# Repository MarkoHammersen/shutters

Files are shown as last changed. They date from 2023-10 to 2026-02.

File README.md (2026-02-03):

# ESP32 Shutter Control System
This project implements a **ESP32-based shutter control system** designed for controlling shutter motors via relays, with clear separation between hardware abstraction and business logic.
The system combines **ESP32**, **Microchip MCP23017 I/O expanders**, and **ULN2003A Darlington arrays**, and is implemented in **C++ using PlatformIO with the Arduino framework**.

---

## System Overview
The shutter system consists of:

* An **ESP32** as the central controller
* **MCP23017 I/O expanders** for scalable digital input and output via I²C
* **ULN2003A Darlington transistor arrays** for driving relay coils
* A dedicated **external 5 V power supply** for stable I/O operation

All safety-relevant design aspects (galvanic separation, flyback protection, low coil current) are explicitly addressed in the extern hardware design, which is not part of the schematics attached.

---

## Hardware Architecture

### Inputs (Buttons / Wall Switches)

* Digital inputs are handled by an **MCP23017 configured as input expander**
* Button **press and release events** are captured
* Each input event triggers a **hardware interrupt**
* The interrupt line is connected to the ESP32
* Upon interrupt, the ESP32:

  1. Starts an I²C transaction
  2. Reads the MCP23017 input registers
  3. Determines the exact event (press or release)

This approach ensures:

* Low latency
* Minimal polling
* Efficient I²C bus usage

---

### Outputs (Shutter Actuation)

* Outputs are handled by a second **MCP23017 configured as output expander**
* Output states are sent from the ESP32 via **I²C**
* MCP23017 outputs drive **ULN2003A Darlington arrays**
* The Darlington arrays drive the **relay coils**

#### Relay Driving

* Relay coil current is low enough to be **safely driven by ULN2003A**
* **Flyback diodes** are mounted directly at the relay coils
* This protects the Darlington arrays and improves EMC robustness

> ⚠️ **Note:** Mains voltage must only be handled by qualified personnel.
---

### Power Supply

* All MCP23017 inputs and outputs are powered by a **stable external 5 V supply**
* This ensures:

  * Reliable logic levels
  * Noise immunity
  * Stable operation independent of ESP32 load conditions

---

## Software Architecture

The firmware is written in **C++** and built using:

* **PlatformIO**
* **Arduino framework**
* **ESP32 target**

The software is cleanly structured into three main layers using dedicated FreeRTOS tasks. The communication between these tasks are done via message queues:

### 1. Sensors

* Abstraction of all input devices
* MCP23017 input handling
* Interrupt processing
* Debouncing and event detection (press / release)

### 2. Actuators

* Abstraction of all output devices
* MCP23017 output handling
* Relay control logic
* Hardware-independent actuator interface

### 3. Shutter Business Logic

* High-level shutter control logic
* Direction handling (up / down)
* Timing and safety constraints
* Mutual exclusion of motor directions

#### State Machine

The business logic is implemented using a **state machine** based on:

👉 **Quantum Leaps – State-Oriented Programming**
[https://github.com/QuantumLeaps/State-Oriented-Programming](https://github.com/QuantumLeaps/State-Oriented-Programming)

This provides:

* Explicit, deterministic state handling
* Clear separation of states and events
* Improved maintainability and testability
* Robust behavior for asynchronous events (buttons, interrupts)

---

## Documentation & Schematics

* Hardware schematics are included in the repository

---

## Key Features

* ESP32-based central control
* Interrupt-driven input handling
* Scalable I/O via MCP23017
* Safe relay driving using ULN2003A
* Clear separation of concerns in software
* State-machine-driven business logic

---
### ⚠️ WARNING

This project uses electromechanical actuators.
Improper handling can result in serious injury, fire, or death.

This project is provided for educational and experimental purposes only.
The author assumes no liability for any damage, injury, or loss resulting
from the use, misuse, or modification of this hardware or software.

Only qualified personnel should work with mains voltage systems.

---
This project is not certified for commercial or residential use.
No compliance with CE, VDE, UL, or any other safety standard is claimed.
--
Use at your own risk!

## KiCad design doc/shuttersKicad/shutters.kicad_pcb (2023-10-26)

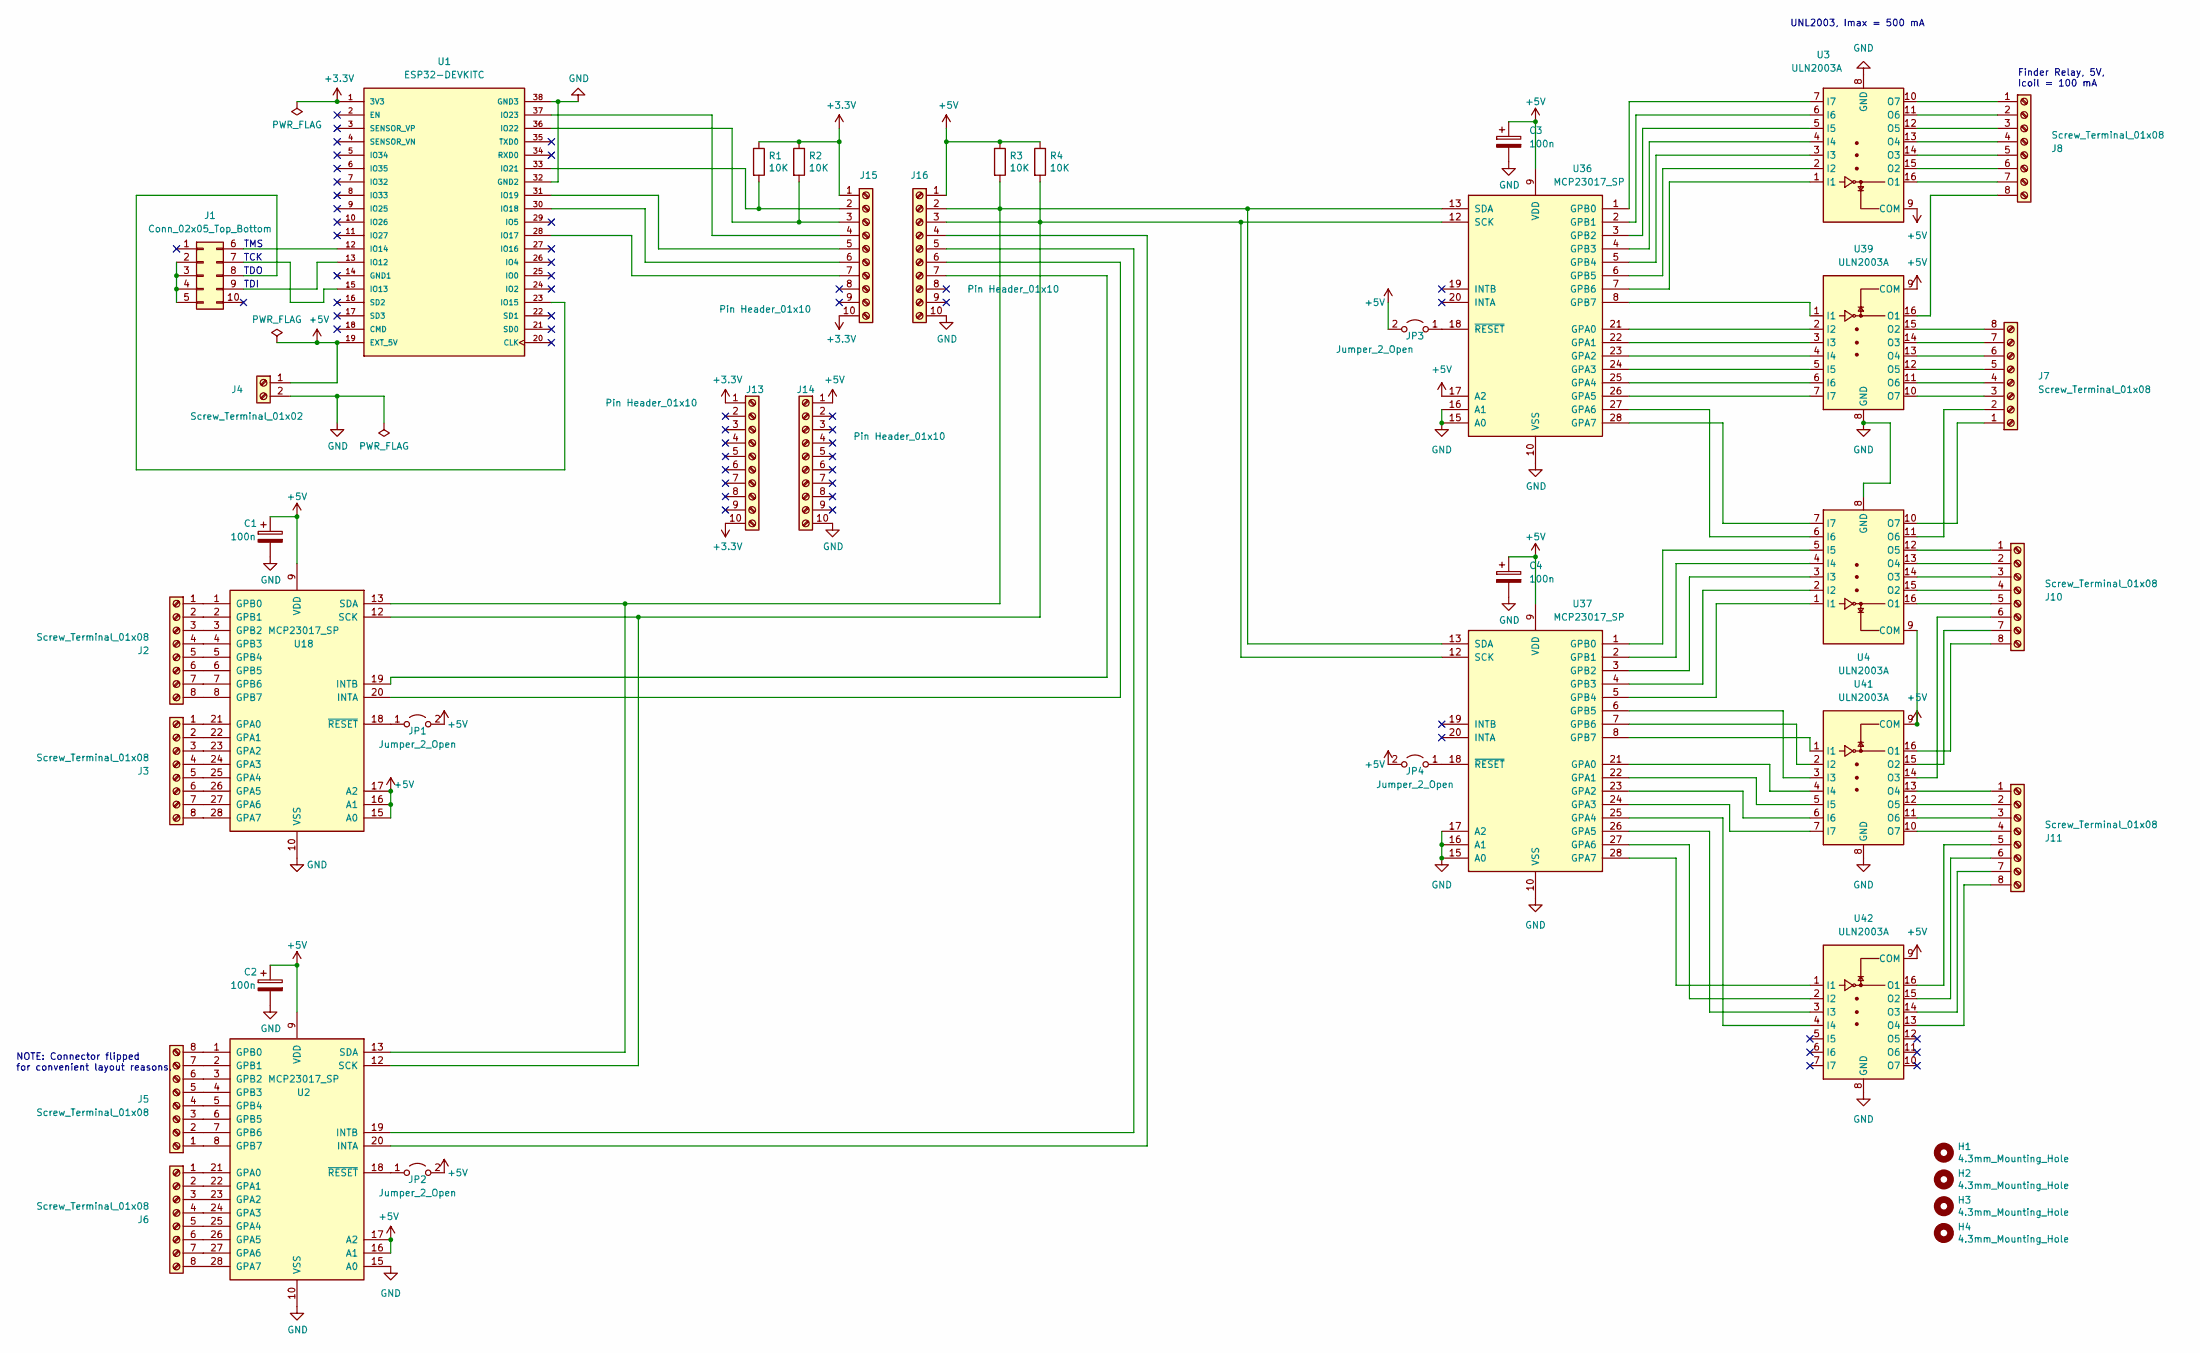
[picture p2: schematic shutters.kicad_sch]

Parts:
C1, C2, C3, C4: 100n; C_Rect_L7.0mm_W2.5mm_P5.00mm
H1, H2, H3, H4: 4.3mm_Mounting_Hole; MountingHole_4.3mm_M4
J1: Conn_02x05_Top_Bottom; PinHeader_2x05_P2.54mm_Vertical
J2, J3, J5, J6, J7, J8, J10, J11: Screw_Terminal_01x08; TerminalBlock_Phoenix_MKDS-1,5-8-5.08_1x08_P5.08mm_Horizont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
J4: Screw_Terminal_01x02; TerminalBlock_Phoenix_MKDS-1,5-2-5.08_1x02_P5.08mm_Horizont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
J13, J14, J15, J16: Pin Header_01x10; PinHeader_1x10_P2.54mm_Vertical
JP1, JP2, JP3, JP4: Jumper_2_Open; PinHeader_1x02_P2.54mm_Vertical
R1, R2, R3, R4: 10K; R_Axial_DIN0204_L3.6mm_D1.6mm_P5.08mm_Horizontal
U1: ESP32-DEVKITC; MODULE_ESP32-DEVKITC; PARTREV N/A
U2, U18, U36, U37: MCP23017_SP; DIP-28_W7.62mm
U3, U4, U39, U41, U42: ULN2003A; DIP-16_W7.62mm_Socket

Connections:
+3V3: J13.1, J13.10, J15.1, J15.10, R1.1, R2.1, U1.1 (3V3)
+5V: C1.1, C2.1, C3.1, C4.1, J4.1, J14.1, J16.1, JP1.2 (B), JP2.2 (B), JP3.2 (B), JP4.2 (B), R3.1, R4.1, U1.19 (EXT_5V), U2.9 (VDD), U2.16 (A1), U2.17 (A2), U3.9 (COM), U4.9 (COM), U18.9 (VDD), U18.15 (A0), U18.16 (A1), U18.17 (A2), U36.9 (VDD), U36.17 (A2), U37.9 (VDD), U39.9 (COM), U41.9 (COM), U42.9 (COM)
GND: C1.2, C2.2, C3.2, C4.2, J4.2, J14.10, J16.10, U1.32 (GND2), U1.38 (GND3), U2.10 (VSS), U2.15 (A0), U3.8 (GND), U4.8 (GND), U18.10 (VSS), U36.10 (VSS), U36.15 (A0), U36.16 (A1), U37.10 (VSS), U37.15 (A0), U37.16 (A1), U37.17 (A2), U39.8 (GND), U41.8 (GND), U42.8 (GND)
unnamed: J1.2, J1.3, J1.4, J1.5
unnamed: J1.6, U1.12 (IO14)
unnamed: J1.7, U1.15 (IO13)
unnamed: J1.8, U1.23 (IO15)
unnamed: J1.9, U1.13 (IO12)
unnamed: J2.1, U18.1 (GPB0)
unnamed: J2.2, U18.2 (GPB1)
unnamed: J2.3, U18.3 (GPB2)
unnamed: J2.4, U18.4 (GPB3)
unnamed: J2.5, U18.5 (GPB4)
unnamed: J2.6, U18.6 (GPB5)
unnamed: J2.7, U18.7 (GPB6)
unnamed: J2.8, U18.8 (GPB7)
unnamed: J3.1, U18.21 (GPA0)
unnamed: J3.2, U18.22 (GPA1)
unnamed: J3.3, U18.23 (GPA2)
unnamed: J3.4, U18.24 (GPA3)
unnamed: J3.5, U18.25 (GPA4)
unnamed: J3.6, U18.26 (GPA5)
unnamed: J3.7, U18.27 (GPA6)
unnamed: J3.8, U18.28 (GPA7)
unnamed: J5.1, U2.8 (GPB7)
unnamed: J5.2, U2.7 (GPB6)
unnamed: J5.3, U2.6 (GPB5)
unnamed: J5.4, U2.5 (GPB4)
unnamed: J5.5, U2.4 (GPB3)
unnamed: J5.6, U2.3 (GPB2)
unnamed: J5.7, U2.2 (GPB1)
unnamed: J5.8, U2.1 (GPB0)
unnamed: J6.1, U2.21 (GPA0)
unnamed: J6.2, U2.22 (GPA1)
unnamed: J6.3, U2.23 (GPA2)
unnamed: J6.4, U2.24 (GPA3)
unnamed: J6.5, U2.25 (GPA4)
unnamed: J6.6, U2.26 (GPA5)
unnamed: J6.7, U2.27 (GPA6)
unnamed: J6.8, U2.28 (GPA7)
unnamed: J7.1, U4.10 (O7)
unnamed: J7.2, U4.11 (O6)
unnamed: J7.3, U39.10 (O7)
unnamed: J7.4, U39.11 (O6)
unnamed: J7.5, U39.12 (O5)
unnamed: J7.6, U39.13 (O4)
unnamed: J7.7, U39.14 (O3)
unnamed: J7.8, U39.15 (O2)
unnamed: J8.1, U3.10 (O7)
unnamed: J8.2, U3.11 (O6)
unnamed: J8.3, U3.12 (O5)
unnamed: J8.4, U3.13 (O4)
unnamed: J8.5, U3.14 (O3)
unnamed: J8.6, U3.15 (O2)
unnamed: J8.7, U3.16 (O1)
unnamed: J8.8, U39.16 (O1)
unnamed: J10.1, U4.12 (O5)
unnamed: J10.2, U4.13 (O4)
unnamed: J10.3, U4.14 (O3)
unnamed: J10.4, U4.15 (O2)
unnamed: J10.5, U4.16 (O1)
unnamed: J10.6, U41.14 (O3)
unnamed: J10.7, U41.15 (O2)
unnamed: J10.8, U41.16 (O1)
unnamed: J11.1, U41.13 (O4)
unnamed: J11.2, U41.12 (O5)
unnamed: J11.3, U41.11 (O6)
unnamed: J11.4, U41.10 (O7)
unnamed: J11.5, U42.16 (O1)
unnamed: J11.6, U42.15 (O2)
unnamed: J11.7, U42.14 (O3)
unnamed: J11.8, U42.13 (O4)
unnamed: J15.2, R1.2, U1.33 (IO21)
unnamed: J15.3, R2.2, U1.36 (IO22)
unnamed: J15.4, U1.37 (IO23)
unnamed: J15.5, U1.31 (IO19)
unnamed: J15.6, U1.30 (IO18)
unnamed: J15.7, U1.28 (IO17)
unnamed: J16.2, R3.2, U2.13 (SDA), U18.13 (SDA), U36.13 (SDA), U37.13 (SDA)
unnamed: J16.3, R4.2, U2.12 (SCK), U18.12 (SCK), U36.12 (SCK), U37.12 (SCK)
unnamed: J16.4, U2.20 (INTA)
unnamed: J16.5, U2.19 (INTB)
unnamed: J16.6, U18.20 (INTA)
unnamed: J16.7, U18.19 (INTB)
unnamed: JP1.1 (A), U18.18 (~RESET)
unnamed: JP2.1 (A), U2.18 (~RESET)
unnamed: JP3.1 (A), U36.18 (~RESET)
unnamed: JP4.1 (A), U37.18 (~RESET)
unnamed: U3.1 (I1), U36.7 (GPB6)
unnamed: U3.2 (I2), U36.6 (GPB5)
unnamed: U3.3 (I3), U36.5 (GPB4)
unnamed: U3.4 (I4), U36.4 (GPB3)
unnamed: U3.5 (I5), U36.3 (GPB2)
unnamed: U3.6 (I6), U36.2 (GPB1)
unnamed: U3.7 (I7), U36.1 (GPB0)
unnamed: U36.8 (GPB7), U39.1 (I1)
unnamed: U36.21 (GPA0), U39.2 (I2)
unnamed: U36.22 (GPA1), U39.3 (I3)
unnamed: U36.23 (GPA2), U39.4 (I4)
unnamed: U36.24 (GPA3), U39.5 (I5)
unnamed: U36.25 (GPA4), U39.6 (I6)
unnamed: U36.26 (GPA5), U39.7 (I7)
unnamed: U4.6 (I6), U36.27 (GPA6)
unnamed: U4.7 (I7), U36.28 (GPA7)
unnamed: U4.5 (I5), U37.1 (GPB0)
unnamed: U4.4 (I4), U37.2 (GPB1)
unnamed: U4.3 (I3), U37.3 (GPB2)
unnamed: U4.2 (I2), U37.4 (GPB3)
unnamed: U4.1 (I1), U37.5 (GPB4)
unnamed: U37.6 (GPB5), U41.3 (I3)
unnamed: U37.7 (GPB6), U41.2 (I2)
unnamed: U37.8 (GPB7), U41.1 (I1)
unnamed: U37.21 (GPA0), U41.4 (I4)
unnamed: U37.22 (GPA1), U41.5 (I5)
unnamed: U37.23 (GPA2), U41.6 (I6)
unnamed: U37.24 (GPA3), U41.7 (I7)
unnamed: U37.25 (GPA4), U42.4 (I4)
unnamed: U37.26 (GPA5), U42.3 (I3)
unnamed: U37.27 (GPA6), U42.2 (I2)
unnamed: U37.28 (GPA7), U42.1 (I1)

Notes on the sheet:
UNL2003, Imax = 500 mA
Finder Relay, 5V, Icoil = 100 mA
TMS
TCK
TDO
NOTE: Connector flipped for convenient layout reasons.
TDI

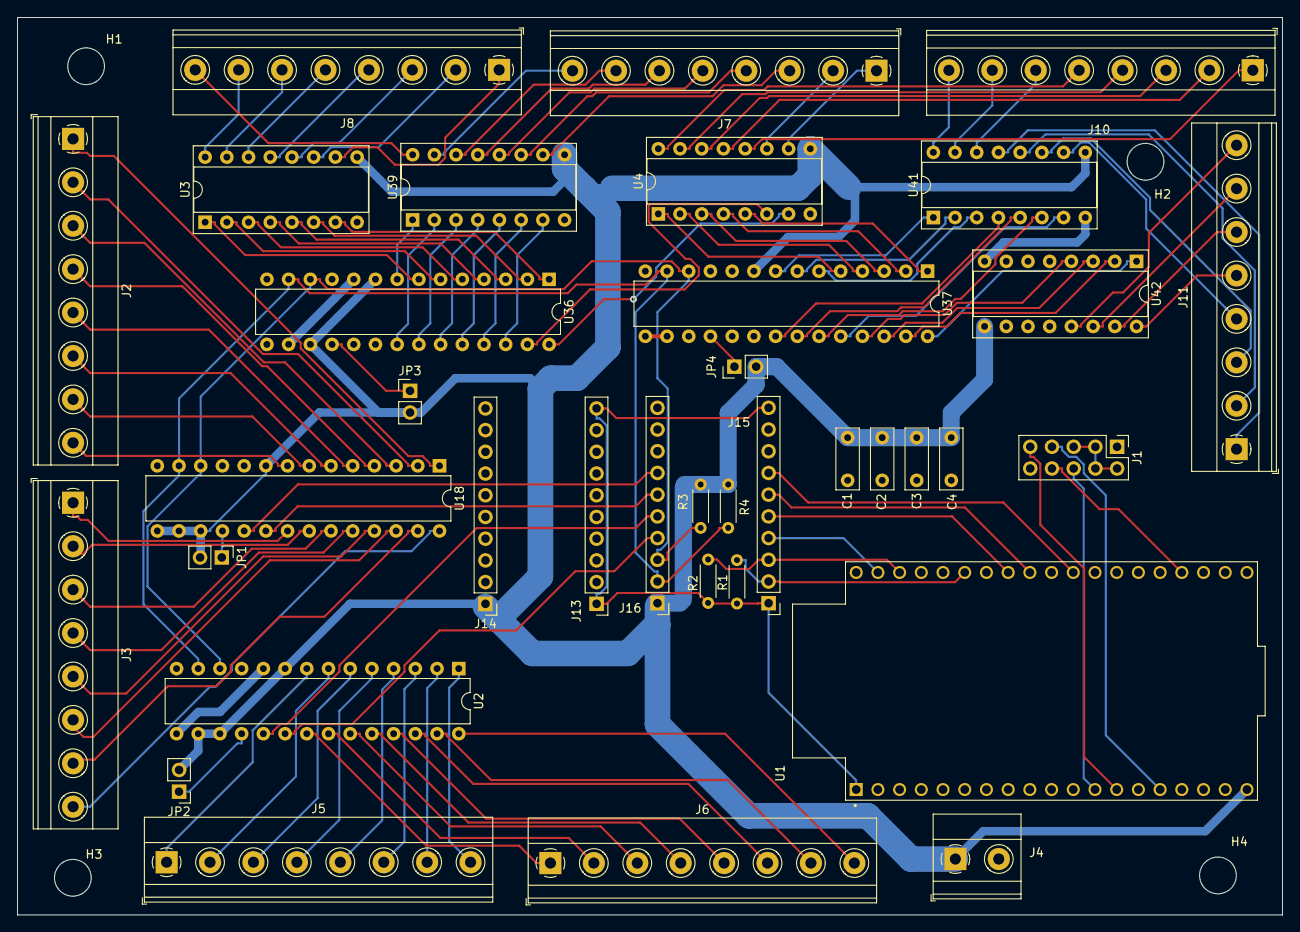
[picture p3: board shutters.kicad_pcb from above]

Board: 2 copper layers, 148.0 x 105.0 mm, 40 parts (0 on the bottom side), 120 nets.

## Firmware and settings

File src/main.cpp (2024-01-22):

#include <Arduino.h>
#include <Wire.h>
#include "Message.h"
#include "MCP23017.h"

extern void initShutterTask();
extern void initActuatorTask();
extern void initSensorTask();

void setup()
{
  ESP_LOGI("main", "setup ENTRY");
  Wire.begin(I2C_SDA, I2C_SCL, I2C_FRQ);
  initActuatorTask();
  delay(20); // allow actuators some time to turn off all outputs
  initShutterTask();
  initSensorTask();
  
  ESP_LOGI("main", "setup EXITY");
}

void testActuators(void)
{
  static bool pressed = false;
  static bool on = false;
  if (digitalRead(0) == LOW)
  {
    appMessage_t msg;
    msg.i2cAddr = I2C_ADDR_ACTUATOR_U37;
    static int pin = 0;
    if (!pressed)
    {
      pressed = true;

      if (!on)
      {
        on = true;
        msg.evt = AppEvents::RUN;
        msg.data = pin;
        log_i("BOOT pin: %02x: pin = %d", msg.i2cAddr, msg.data);
        assert(pdTRUE == xQueueSend(qHandleActuators, &msg, portMAX_DELAY));
      }
      else
      {
        on = false;
        msg.evt = AppEvents::STOP;
        msg.data = pin++;
        log_i("BOOT pin: %02x: pin = %d", msg.i2cAddr, msg.data);
        assert(pdTRUE == xQueueSend(qHandleActuators, &msg, portMAX_DELAY));
      }
    }
  }
  else
  {
    pressed = false;
  }
}


void loop()
{
#if 0 // for testing actuators
testActuators();
#endif
}

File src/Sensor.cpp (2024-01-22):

#include <Arduino.h>
#include <arduino-timer.h>
#include <107-Arduino-CriticalSection.h>
#include <vector>
#include "Message.h"
#include "MCP23017.h"
#include "Sensor.h"

static SemaphoreHandle_t iSRSemaphore = nullptr;
static TaskHandle_t xHandleSensors = NULL;
static std::vector<Sensor> vSensors = {
    {Sensor("U2",
            I2C_ADDR_SENSOR_U2,
            SENSOR_U2_INTA,
            SENSOR_U2_INTB,
            Wire)},
    {Sensor("U18",
            I2C_ADDR_SENSOR_U18,
            SENSOR_U18_INTA,
            SENSOR_U18_INTB,
            Wire)}};

static void sensorInterrupt()
{
    BaseType_t xHigherPriorityTaskWoken = pdFALSE;
    xSemaphoreGiveFromISR(iSRSemaphore, &xHigherPriorityTaskWoken);
    if (xHigherPriorityTaskWoken)
    {
        portYIELD_FROM_ISR();
    }
}

static void sensorInterruptU2A(void)
{
    sensorInterrupt();
}
static void sensorInterruptU2B(void)
{
    sensorInterrupt();
}
static void sensorInterruptU18A(void)
{
    sensorInterrupt();
}
static void sensorInterruptU18B(void)
{
    sensorInterrupt();
}

static void vTaskSensor(void *arg)
{
    ESP_LOGI("Sensor", "task ENTRY");

    // initialize semaphore for reader task
    iSRSemaphore = xSemaphoreCreateBinary();

    for (uint32_t i = 0; i < vSensors.size(); i++)
    {
        vSensors[i].init();
        pinMode(vSensors[i].getPinIntPort(MCP23017Port::A), INPUT);
        pinMode(vSensors[i].getPinIntPort(MCP23017Port::B), INPUT);
    }

    attachInterrupt(digitalPinToInterrupt(SENSOR_U2_INTA), sensorInterruptU2A, CHANGE);
    attachInterrupt(digitalPinToInterrupt(SENSOR_U2_INTB), sensorInterruptU2B, CHANGE);
    attachInterrupt(digitalPinToInterrupt(SENSOR_U18_INTA), sensorInterruptU18A, CHANGE);
    attachInterrupt(digitalPinToInterrupt(SENSOR_U18_INTB), sensorInterruptU18B, CHANGE);

    while (1)
    {
        if (xSemaphoreTake(iSRSemaphore, portMAX_DELAY) == pdPASS)
        {
            for (uint32_t i = 0; i < vSensors.size(); i++)
            {
                if ((LOW == digitalRead(vSensors[i].getPinIntPort(MCP23017Port::A))) || (LOW == digitalRead(vSensors[i].getPinIntPort(MCP23017Port::B))))
                {
                    uint16_t gpioAB;
                    if (true == vSensors[i].getGpioAB(&gpioAB))
                    {
                        log_i("%s interrupt: %04x", vSensors[i].getName(), gpioAB);
                        appMessage_t msg;
                        msg.i2cAddr = vSensors[i].getI2cAddr();
                        msg.evt = AppEvents::TOUCH;
                        msg.data = gpioAB;
                        xQueueSend(qHandleShutters, &msg, portMAX_DELAY);
                    }

                    delay(50);

                    // repeat giving the semaphore until digitalRead returns a high signal on the INT pins
                    xSemaphoreGive(iSRSemaphore);
                }
            }
        }
    }
}

void initSensorTask(void)
{
    xTaskCreate(vTaskSensor, "sensor", 4096, NULL, 10, &xHandleSensors);
    configASSERT(xHandleSensors != NULL);
}

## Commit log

2023-10-20 pin assignment
2023-10-26 edit kicad
    [shutters.kicad_pcb, shutters.kicad_sch]
2024-01-20 Sensor reading and releasing complete
2024-01-20 tests of actuators ok
2024-01-22 pin configuration
2026-02-03 Update README with project details and architecture
    Added detailed project description, system overview, hardware and software architecture, and key features for the ESP32 Shutter Control System.
2026-02-03 Revise README for clarity and safety warnings
    Updated project description and added warning about electromechanical actuators and safety compliance.
